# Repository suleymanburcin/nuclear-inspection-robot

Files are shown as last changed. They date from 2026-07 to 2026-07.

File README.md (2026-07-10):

# Nükleer Denetim Robotu

**TEKNOFEST 2026 · Nükleer Enerji Teknolojileri Tasarım Yarışması**
Uygulama Kategorisi — Robotik Sistem Tasarımı

Küçük ve mikro modüler reaktörlerde (SMR/MMR) insan girişi olmadan denetim yapmak üzere
geliştirilmiş, **keseli (marsupial)** mimariye sahip iki platformlu robotik sistem.

---

## Fikir

Kaza sonrası bir nükleer tesiste iki farklı problem vardır ve bunların çözümleri
birbiriyle çelişir:

- **Dış sahada** menzil ve yük taşıma kapasitesi gerekir → yüksek özgül enerjili yakıt
- **Reaktör binası içinde** kıvılcım ve egzoz üretilmemelidir → hidrojen birikimi riski

Literatürdeki robotlar tek platformlu ve tamamen elektriklidir; ikinci kısıtı sağlarlar
ama birincisinden ödün verirler.

Bu çalışma görevi **iki uzmanlaşmış platforma** ayırır:

| Platform | Tahrik | Görev |
|---|---|---|
| **Benzinli taşıyıcı** | 7 BG içten yanmalı, Ackermann direksiyon | Dış saha, menzil, yük |
| **Elektrikli yavru robot** | Deneyap Kart 1A, kayma-yönlendirmeli | Kapalı hacim, emisyonsuz |

Literatürdeki hibritler ağırlıklı olarak *hareket-modu* hibritleridir (tekerlek–palet,
tekerlek–bacak). Buradaki ise bir **enerji-modu hibrididir.**

Kapalı hacme yalnızca emisyonsuz robot girer. Kaza sonrası ortamda hidrojen birikimi
ihtimali göz önüne alındığında bu bir tercih değil, **güvenlik gereğidir.**

Taşıyıcı platform, atıl bir go-kart şasisinden yeniden kazanılmıştır.

---

## Sistem mimarisi

Dört katman, dört ayrı işlemci. Katmanlar fiziksel olarak ayrılmıştır; bu sayede hata
kaynağı ayrıştırılabilir ve alt sistemler paralel geliştirilebilir.

```
  ALGILAMA          KÖPRÜLEME          KARAR              EYLEYİCİ
  Arduino Leonardo  1. ESP32           Jetson Orin Nano   2. ESP32
  10 sensör         BNO055 yönelim     PyQt5 panel        6 eyleyici
       │                 │                  │                  ▲
       └──D0/D1─────────►└──GPIO2──────────►└──pin8────────────┘
          115.200            JSON              M,…*XOR
```

Buna ek olarak, karar katmanından **tamamen yalıtılmış** bir FPV hattı bulunur:
termal kamera ve radyasyon dedektörünün ekranları ortak bir kadrajda, analog video
üzerinden operatöre aktarılır. Jetson çökse dahi radyolojik ve termal durum
farkındalığı sürer.

---

## Doğrulanmış işlevler

- Manuel kontrollü sürüş: gaz, fren, direksiyon
- Çok modaliteli algılama: beş gaz kanalı (H₂, CO, LPG/duman, NH₃/CO₂, UOB),
  sıcaklık/nem/basınç, ultrasonik seviye, GNSS, dokuz eksen mutlak yönelim
- Her iki platformda üç eksenli manipülatör
- Elektrikli yavru robotun kablosuz denetimi ve emniyet zaman aşımı
- Çift kameralı görüş, RealSense derinlik akışı
- Karar katmanından bağımsız FPV hattı (termal + radyasyon)
- Yalıtılmış ağda salt-okunur panel yayını (MJPEG, çoklu istemci)
- Uzaktan kontrol: fiziksel joystick her zaman öncelikli

## Doğrulanmamış / kapsam dışı

Bunlar raporda da açıkça belirtilmiştir; hiçbiri görev senaryolarının başarı
ölçütüne dâhil değildir.

- **Otonom seyrüsefer** — planlama katmanı yazıldı, eyleyici katmanına bağlanmadı,
  saha denemesi yapılmadı. İç mekân modülünde **lokalizasyon yoktur**; robot kendi
  konumunu ölçmez, konum varsayılır.
- **Yüksek tork gerektiren manipülasyon** — mevcut aktüatör kapasitesi dışında.
- **Zırhlamanın fiziksel doğrulaması** — yalnızca Geant4 simülasyonu yapıldı,
  ışınlama testi yapılmadı.

---

## Radyasyon zırhlaması

COTS bileşenlerin literatürde bildirilen **~120 Gy** arıza eşiği veri olarak alınmış,
bu eşiğin altında kalınmasını sağlayacak zırhlama Geant4 ile boyutlandırılmıştır.
Böylece dayanım problemi, pahalı bileşen tedarikinden **ölçülebilir bir mühendislik
hesabına** dönüşmüştür.

| Malzeme | Gama 1,6 MeV | Nötron 2 MeV |
|---|---|---|
| WNiFe95 | %7,93 | %36,80 |
| **WNiFe97** | **%7,40** | **%36,22** |
| WNiCu97 | %7,53 | %36,37 |
| Cam (Pb + boro) | %57,18 | %70,88 |

Seçilen yapılandırma: **1 cm parafin + 4 cm WNiFe97**. Parafin hızlı nötronları elastik
saçılmayla yavaşlatır; tungsten alaşımı gama fotonlarını soğurur ve parafindeki nötron
yakalanmasından doğan ikincil gamaları da zayıflatır.

---

## Depo yapısı

```
geant4/           Zırhlama analizi: girdi makrosu, koşu çıktıları, kaynak
firmware/         Gömülü yazılım — dört Arduino eskizi
  leonardo_gas_sender/    Algılama katmanı
  esp32_1_bridge/         Köprüleme katmanı
  esp32_2_actuator/       Eyleyici katmanı
  deneyap_baby/           Elektrikli yavru robot
jetson/           Karar katmanı ve seyrüsefer modülleri
  remote_control/         Uzak istasyon istemcisi
cad/              Üç boyutlu baskı parçalarının teknik çizimleri
```

---

## Kurulum

### Gömülü kartlar (Arduino IDE)

> **ÖNEMLİ.** ESP32 kart tanımı yanlış seçilirse `Serial2` sessizce ölür.

```
Board            : ESP32 Dev Module      ← "Wrover Kit" DEĞİL
PSRAM            : Disabled
Flash Mode       : DIO
Flash Frequency  : 40MHz
Upload Speed     : 115200
Core Debug Level : None
```

PSRAM açıkken çekirdek **GPIO16 ve GPIO17'yi PSRAM için ayırır.** `Serial2` bu iki
pinde olduğundan komutlar hiç ulaşmaz. Firmware bunu derleme zamanında engeller:

```c
#ifdef BOARD_HAS_PSRAM
#error "PSRAM ACIK! GPIO16/17 PSRAM'e ayrilir, Serial2 calismaz."
#endif
```

Gerekli kütüphaneler: `ESP32Servo` · `Adafruit BNO055` · `Adafruit BME280` · `TinyGPS++`

### Wi-Fi kimlik bilgileri

`firmware/deneyap_baby/secrets_ornek.h` dosyasını `secrets.h` olarak kopyalayıp doldurun.
`secrets.h` `.gitignore` içindedir; **depoya yüklenmez.**

### Karar katmanı (Jetson Orin Nano)

```bash
pip3 install -r jetson/requirements.txt
python3 jetson/jetson_gas_dock.py
```

---

## Haberleşme protokolleri

| Hat | Biçim | Hız |
|---|---|---|
| Leonardo → 1. ESP32 | 17 alanlı çerçeve + XOR sağlama | 115.200 |
| 1. ESP32 → Jetson | JSON | 115.200 |
| Jetson → 2. ESP32 | `M,gaz,fren,dir,kolBaz,dirsek,parmak*XOR` | 115.200 |
| Jetson → Deneyap | `F,s1,s2,s3` (UDP yayını) | :4210 |
| Uzak istasyon → Jetson | `joyX,joyY` (UDP) | :9000 |

Komut hatlarında **XOR sağlama toplamı** kullanılır. Gürültülü bir hatta bozulan çerçeve,
eyleyiciye ulaşmadan elenir. Bu, gaz kelebeğinin yanlış bir baytla açılmasını engeller.

---

## Güvenlik

- Panel yayını (`:8080`) ve uzaktan kontrol (`:9000`) **yalıtılmış yerel ağda** kalmalıdır.
  Kimlik doğrulama ve TLS **yoktur**; internete açılmamalıdır. Yalıtım ağ düzeyinde
  sağlanır, uygulama düzeyinde değil.
- Yayın arayüzü **salt-okunurdur.** Yalnızca `GET` yöntemini ve üç tanımlı yolu işler;
  hiçbir eyleyici uç noktası yayımlamaz. Arayüz ele geçirilse dahi robota komut verilemez.
- Uzaktan kontrolde **fiziksel joystick her zaman önceliklidir.** Araç üzerindeki kol
  merkezden ayrıldığı anda uzak komut yok sayılır.
- Üç bağımsız emniyet katmanı: fiziksel öncelik → 800 ms uzak zaman aşımı →
  1500 ms eyleyici zaman aşımı (gaz kapanır).

---

## Geliştirme sırasında belgelenen hata sınıfları

Literatürde nadiren paylaşılan, gerçek bir gömülü sistemde karşılaşılan altı hata sınıfı
raporun 4.1.2.8 bölümünde kök nedenleriyle birlikte açıklanmıştır. Aralarında:

- **Kart tanımının PSRAM'li seçilmesi** → UART2 pinlerinin işgali → sessiz haberleşme kaybı
- **Kanal kapasitesi** — 9600 baud, 25 Hz'te üretilen çerçeveyi taşıyamaz (212 ms > 40 ms)
- **Sürücü asgari darbe genişliği** — adım motoru sürücüsünün gereksinimi
- **Sensör önyükleme penceresi** — BNO055'in I²C'ye hazır olma süresi

Bu bulguların paylaşılması, benzer sistemleri geliştirecek ekiplerin aynı hatalara
harcayacağı süreyi kısaltır.

---

## Maliyet

Toplam donanım maliyeti yaklaşık **129.045 ₺**. Ticari nükleer denetim robotlarının
maliyetinin çok altındadır; sistem tamamen ticari raf ürünü bileşenler ve açık kaynaklı
bir araç zinciri üzerine kuruludur. **Tescilli yazılım bağımlılığı yoktur.**

---

## Lisans ve atıf

TEKNOFEST 2026 Nükleer Enerji Teknolojileri Tasarım Yarışması kapsamında geliştirilmiştir.

Bu depoyu kullanır veya alıntılarsanız, projeye atıf yapmanız beklenir.

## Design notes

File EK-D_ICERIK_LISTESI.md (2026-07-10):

# Ek-D · Dijital Eklerin İçerik Listesi

Bu arşiv, Final Değerlendirme Raporu'nun **Ek-D** bölümünde tanımlanan yapıya birebir
uygundur.

| Klasör / dosya | İçerik | Durum |
|---|---|---|
| `geant4/utku.mac` | Zırhlama analizi girdi makrosu (Ek-A ile aynı) | ✅ |
| `geant4/output/*.txt` | Beş zırh yapılandırmasının tam koşu çıktıları | ✅ |
| `geant4/src/DetectorConstruction.cc` | Zırh malzemeleri ve geometri tanımı | ✅ |
| `firmware/leonardo_gas_sender/` | Algılama katmanı gömülü yazılımı | ✅ |
| `firmware/esp32_1_bridge/` | Köprüleme katmanı gömülü yazılımı | ✅ |
| `firmware/esp32_2_actuator/` | Eyleyici katmanı gömülü yazılımı | ✅ |
| `firmware/deneyap_baby/` | Elektrikli yavru robot gömülü yazılımı | ✅ |
| `jetson/requirements.txt` | Python paketlerinin sürüm listesi | ✅ Tablo 8.4’ten üretildi |
| `jetson/jetson_gas_dock.py` | Gösterge paneli ve MJPEG yayın sunucusu | ✅ |
| `jetson/remote_control/` | Uzak istasyon istemcisi | ✅ |
| `jetson/indoor_nav.py` | İç mekân yol planlama modülü | ✅ |
| `jetson/outdoor_nav.py` | Dış mekân rota takibi modülü | ✅ |
| `cad/` | Üç boyutlu baskı parçalarının teknik çizimleri | ✅ 12 STL |

## Ek-D'de listelenmeyen, arşive dâhil edilen dosyalar

| Dosya | Neden |
|---|---|
| `firmware/deneyap_baby/secrets_ornek.h` | Wi-Fi kimlik bilgisi şablonu; gerçek değerler depoda tutulmaz |
| `jetson/outdoor_nav_gui.py` | Dış mekân seyrüsefer izleme arayüzü |
| `jetson/rover_gcs.py` | Uydu haritalı yer kontrol istasyonu |

Bu üç dosya raporun Ek-C bölümünde kaynak kod olarak yer almaktadır.

---

## Geant4 koşu ayarları (çıktı dosyalarından doğrulandı)

| | |
|---|---|
| Sürüm | `geant4-11-03-patch-02 [MT]` |
| Fizik listesi | `QGSP_BERT_HP` |
| Birincil parçacık | 10⁶ / parçacık türü |

---

## Yüklemeden önce yapılacaklar

1. `geant4/output/CAM.txt` (cam yapılandırması koşu çıktısı) dosyasını ekleyin.
2. `cad/fpv_tutucu.stl` ve `cad/kol_taban_braketi.stl` adlandırmalarını doğrulayın.
3. `secrets.h` dosyasının arşivde **bulunmadığını** doğrulayın.

---

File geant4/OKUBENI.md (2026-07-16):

# geant4/ — Radyasyon Zırhlama Analizi

## Koşu ayarları (çıktı dosyalarından doğrulanmıştır)

| | |
|---|---|
| Geant4 sürümü | `geant4-11-03-patch-02 [MT]` (çok iş parçacıklı) |
| Fizik listesi | `QGSP_BERT_HP` |
| Birincil parçacık | 10⁶ / parçacık türü |
| Panel kesiti | 10 cm × 10 cm |

Dört çıktı dosyasının tamamı **aynı sürüm ve aynı fizik listesiyle** koşulmuştur;
karşılaştırma bu nedenle geçerlidir.

`QGSP_BERT_HP` seçimi, `_HP` uzantısı sayesinde 20 MeV altındaki nötronlar için
yüksek hassasiyetli veri kütüphanelerini kullanır. Nötron zırhlaması için gereklidir.

## Mevcut dosyalar

| Dosya | İçerik |
|---|---|
| `src/DetectorConstruction.cc` | Zırh malzemeleri ve geometri tanımı (8 malzeme) |
| `output/WNIFE97.txt` | Tungsten–nikel–demir %97 |
| `output/WNIFE95.txt` | Tungsten–nikel–demir %95 |
| `output/WNICU97.txt` | Tungsten–nikel–bakır %97 |
| `output/WNICU95.txt` | Tungsten–nikel–bakır %95 |

## `utku.mac` hakkında

Makro; 1 cm parafin + 4 cm zırh geometrisini kurar, panel kesitini 10 cm × 10 cm yapar
ve on beş koşu yürütür (her biri 10⁶ birincil parçacık):

| Parçacık | Enerji |
|---|---|
| Gama × 6 | 59,5 keV · 364 keV · 605 keV · 662 keV · 796 keV · 1596 keV |
| Beta (e⁻) × 4 | 606 · 512 · 546 keV · 2,28 MeV |
| Alfa × 2 | 5,16 · 5,49 MeV |
| Nötron × 3 | 0,025 eV (termal) · 100 keV (epitermal) · 2 MeV (hızlı) |

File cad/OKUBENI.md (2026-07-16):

# cad/ — Üç Boyutlu Baskı Parçaları

Tüm dosyalar ikili (binary) STL biçimindedir ve bütünlük denetiminden geçmiştir.

## Mevcut parçalar

| Dosya | Üçgen | Parça |
|---|---|---|
| `gaz1.STL` – `gaz4.STL` | 716 / 770 / 1376 / 656 | Gaz kelebeği servosu braketi |
| `fren1.STL`, `fren2.STL` | 766 / 720 | Fren servosu braketi |
| `direksiyon1.STL`, `direksiyon2.STL` | 2112 / 826 | Direksiyon adım motoru braketi |
| `ustkapak.STL` | 1316 | Algılama muhafazası — üst kapak (230 × 200 × 52 mm) |
| `altkapak.STL` | 628 | Algılama muhafazası — alt kapak (230 × 200 × 10 mm) |
| `fpv_tutucu.stl` | 1718 | FPV kamera ve ölçüm cihazı tutucusu (122 × 100 × 190 mm) |
| `kol_taban_braketi.stl` | 26864 | Kol taban adım motoru braketi (75 × 65 × 94 mm) |

.

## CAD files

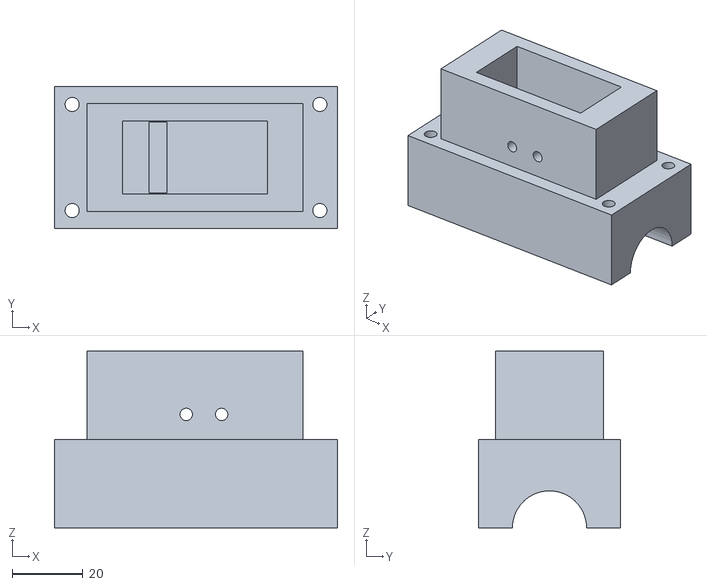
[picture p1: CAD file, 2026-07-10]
cad/gaz3.STL
80.0 x 40.0 x 50.0

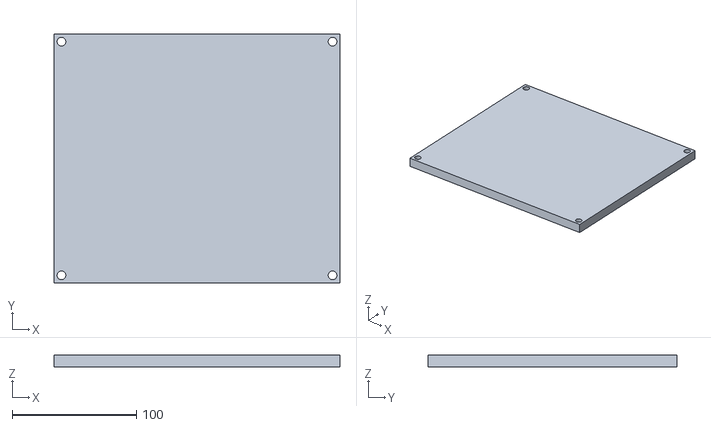
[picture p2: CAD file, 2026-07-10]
cad/altkapak.STL
230.0 x 200.0 x 10.0

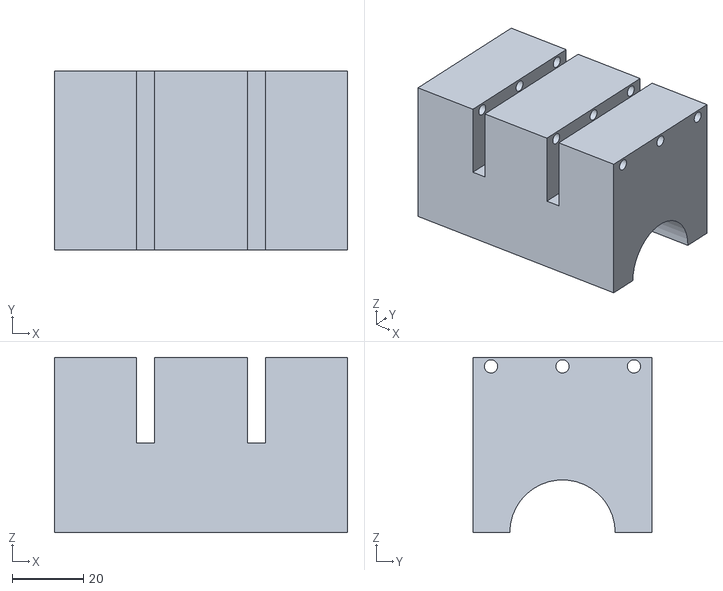
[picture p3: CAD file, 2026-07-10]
cad/direksiyon1.STL
82.0 x 50.0 x 49.0

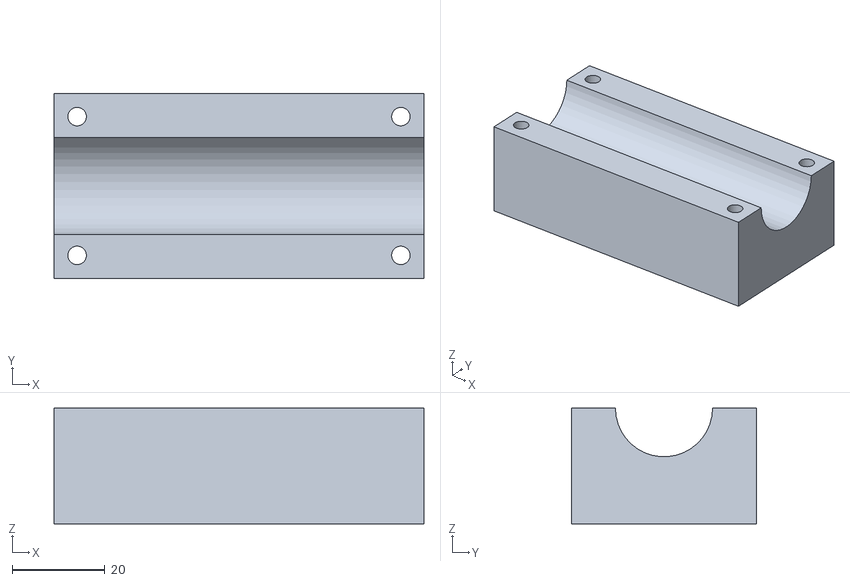
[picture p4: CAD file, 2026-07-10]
cad/gaz1.STL
80.0 x 40.0 x 25.0

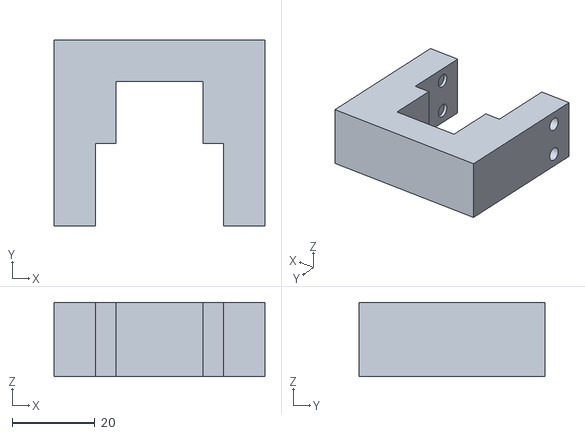
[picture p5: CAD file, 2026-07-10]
cad/gaz4.STL
51.0 x 45.0 x 18.0

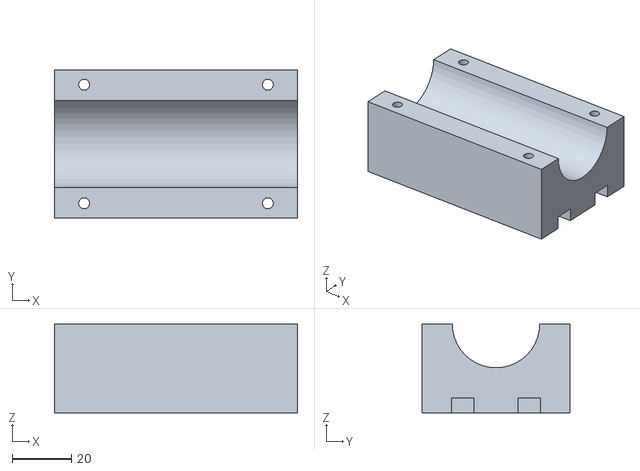
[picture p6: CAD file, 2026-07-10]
cad/direksiyon2.STL
82.0 x 50.0 x 30.0

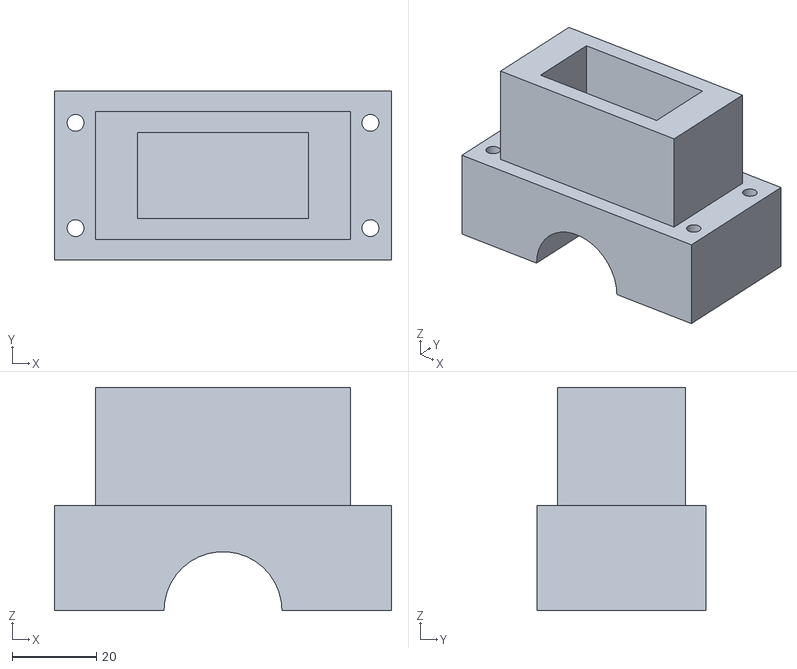
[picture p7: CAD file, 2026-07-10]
cad/fren1.STL
80.0 x 40.0 x 53.0

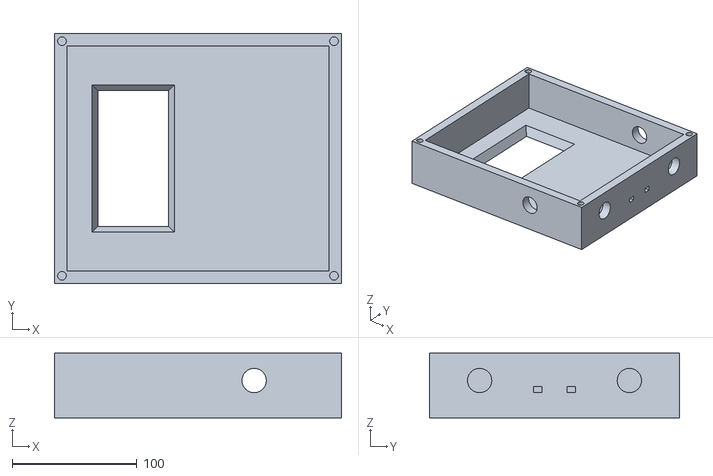
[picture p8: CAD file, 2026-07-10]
cad/ustkapak.STL
230.0 x 200.0 x 52.0

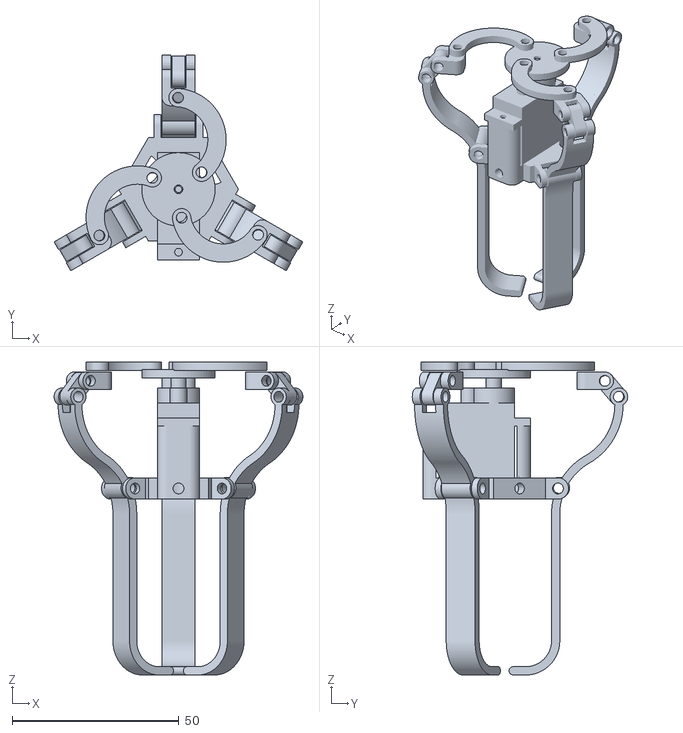
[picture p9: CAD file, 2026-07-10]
cad/kol_taban_braketi.stl
74.7 x 64.7 x 94.0

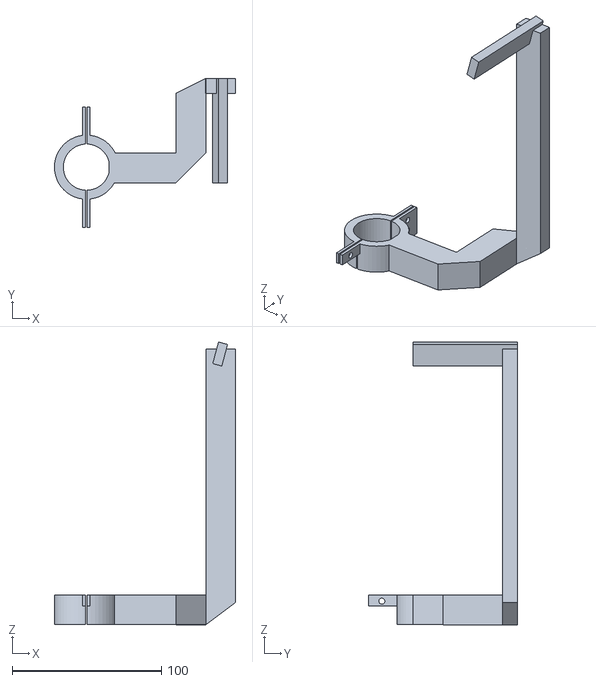
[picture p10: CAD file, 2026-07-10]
cad/fpv_tutucu.stl
121.5 x 100.0 x 189.8

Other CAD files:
cad/gaz2.STL
cad/fren2.STL

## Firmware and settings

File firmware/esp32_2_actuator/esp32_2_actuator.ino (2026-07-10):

/*
 * ============ 2. ESP32 - MOTOR + ROBOT KOL KONTROL ============
 * Jetson'dan komut alir, motorlari + robot kolu surer. SENSOR YOK.
 *
 * BAGLANTI:
 *   Jetson ttyTHS1 TX (pin 8, 3.3V) --> 2. ESP32 GPIO16 (RX2)
 *   Jetson GND (pin 6)              --> 2. ESP32 GND      [ORTAK GND SART]
 *
 * SURUS MOTORLARI:
 *   Servo GAZ    -> GPIO18   (6V ayri guc)
 *   Servo FREN   -> GPIO19
 *   Step DIREKS. -> PUL GPIO26, DIR GPIO27   (MD5042 + 57HB84)
 *
 * ROBOT KOL:
 *   Step TABAN   -> PUL GPIO25, DIR GPIO33   (MD5042 + 57HB84, aynisi)
 *   Servo DIRSEK -> GPIO23    (0-180)
 *   Servo PARMAK -> GPIO22     (0-180, kiskac ac/kapa)
 *   TUM STEP PUL+/DIR+ -> 5V | TUM GUC ORTAK GND
 *
 * KOMUT PROTOKOLU (Jetson -> ESP32, \n sonlu):
 *   M,<gaz>,<fren>,<dir>,<kolBaz>,<dirsek>,<parmak>\n
 *     gaz    : 0..90    (gaz servosu)
 *     fren   : 0..90    (fren servosu)
 *     dir    : -STEER_MAX_LEFT..+STEER_MAX_RIGHT (asimetrik; 0=duz)
 *     kolBaz : -600..600 (kol taban step hedef; 0=merkez)
 *     dirsek : 0..180   (dirsek servosu)
 *     parmak : 0..180   (parmak/kiskac servosu)
 *   Ornek: M,40,0,20,100,90,180  -> yarim gaz, saga, kol saga, dirsek orta, parmak acik
 *   Komut gelmezse (CMD_TIMEOUT = 1500ms): GUVENLIK -> gaz kapa, fren serbest.
 *
 * ACILISTA: direksiyon VE kol tabani ELLE ORTA/DUZ yap (merkez=0).
 * Kutuphane: ESP32Servo
 */

#include <ESP32Servo.h>

// ============================================================================
//  DERLEME KORUMASI — PSRAM
//  PSRAM acikken ESP32 cekirdegi GPIO16 ve GPIO17'yi PSRAM icin ayirir.
//  Serial2 bu iki pinde oldugundan Jetson komutlari HIC ULASMAZ.
//  Belirti: "E (91) psram: PSRAM ID read error" + surekli [GUVENLIK] mesaji.
//  Cozum:   Tools > Board: "ESP32 Dev Module"   ve   Tools > PSRAM: Disabled
// ============================================================================
#ifdef BOARD_HAS_PSRAM
#error "PSRAM ACIK! GPIO16/17 PSRAM'e ayrilir, Serial2 calismaz. Tools > PSRAM: Disabled yap."
#endif


// ---- Jetson komut hatti ----
#define JETSON_RX 16
#define JETSON_TX 17
#define CMD_BAUD  115200

// ---- Surus motor pinleri ----
#define SERVO_GAS_PIN   18   // (yer degistirildi: eskiden 19, ters calisiyordu)
#define SERVO_BRAKE_PIN 19   // (yer degistirildi: eskiden 18)
#define STEER_PUL_PIN   26
#define STEER_DIR_PIN   27

// ---- Robot kol pinleri ----
#define ARM_PUL_PIN     25   // kol taban step
#define ARM_DIR_PIN     33
#define SERVO_ELBOW_PIN 23   // dirsek
#define SERVO_GRIP_PIN  22   // parmak/kiskac (5ten 22ye tasindi)

Servo servoGas, servoBrake, servoElbow, servoGrip;

// ---- Aci limitleri ----
const int GAS_MIN = 0, GAS_MAX = 90;
const int BRK_MIN = 0, BRK_MAX = 90;
const int ELB_MIN = 0, ELB_MAX = 180;
const int GRP_MIN = 0, GRP_MAX = 180;

// ---- Direksiyon step ----
// ---- DIREKSIYON ACI SINIRLARI (asimetrik) ----
// Aci -> adim donusumu: adim = derece * STEPS_PER_REV * GEAR / 360
//   STEPS_PER_REV : surucunun mikroadim ayari (tam tur basina adim)
//   STEER_GEAR    : motor mili -> direksiyon mili orani (dogrudan tahrik = 1.0)
// Degistirmek icin SADECE asagidaki dort satiri duzenle.
// !!! STEER_STEPS_PER_REV, MD5042'nin DIP anahtarindaki mikroadim ayariyla
//     BIREBIR AYNI OLMALI. Uyusmazsa direksiyon eksik/fazla doner.
//     (Onceki deger 400 idi; olculen donusun 1/3 kalmasi uzerine 1200 yapildi.)
const float STEER_STEPS_PER_REV = 1200.0;  // MD5042 mikroadim ayari (DIP'ten oku!)
const float STEER_GEAR          = 1.0;     // dogrudan tahrik (disli/kayis varsa oran gir)
const float STEER_DEG_RIGHT     = 15.0;    // saga azami aci
const float STEER_DEG_LEFT      = 30.0;    // sola azami aci

const long STEER_MAX_RIGHT = (long)(STEER_DEG_RIGHT * STEER_STEPS_PER_REV * STEER_GEAR / 360.0 + 0.5);  // 50 adim
const long STEER_MAX_LEFT  = (long)(STEER_DEG_LEFT  * STEER_STEPS_PER_REV * STEER_GEAR / 360.0 + 0.5);  // 100 adim
const int  STEER_MIN_US = 600;   // darbe 200us + bekleme (adim hizi)
long steerCurrent = 0, steerTarget = 0;
uint32_t lastSteerUs = 0;

// ---- Kol taban step ----
const long ARM_MAX    = 600;   // kol taban +-600 adim (~270 derece, 6 kat)
const int  ARM_MIN_US = 1500;  // kol yavas donsun (adimlar arasi daha genis)
long armCurrent = 0, armTarget = 0;
uint32_t lastArmUs = 0;

// ---- Komut alimi ----
char cmdBuf[80];
uint8_t cmdLen = 0;
uint32_t lastCmdMs = 0;
const uint32_t CMD_TIMEOUT = 1500;  // joystick ~1Hz geldigi icin genis tut (gaz kesilmesin)
bool timeoutWarned = false;   // guvenlik uyarisi bir kez bassin

// ---- Hat kalitesi sayaclari (gurultu teshisi) ----
uint32_t okCount = 0;        // gecerli komut
uint32_t badCount = 0;       // bozuk / sagalama tutmayan satir
uint32_t lastErrMs = 0;      // hata mesajini saniyede 1 kez bas
uint32_t lastStatMs = 0;     // 5 saniyede bir ozet
const bool VERBOSE_HAM = false;  // true yaparsan her satiri ham basar

// Genel bloklamayan step surucu (hangi motor olursa)
void stepTickGeneric(long &cur, long tgt, uint32_t &lastUs, int minUs,
                     int pulPin, int dirPin) {
  if (cur == tgt) return;
  uint32_t now = micros();
  if (now - lastUs < (uint32_t)minUs) return;
  lastUs = now;
  bool dir = (tgt > cur);
  digitalWrite(dirPin, dir ? HIGH : LOW);
  delayMicroseconds(10);          // yon oturması icin
  digitalWrite(pulPin, HIGH);
  delayMicroseconds(100);         // HIGH darbe genisligi (MD5042 icin yeterli)
  digitalWrite(pulPin, LOW);
  delayMicroseconds(100);         // LOW arasi (darbe net ayrilsin)
  cur += dir ? 1 : -1;
}

// Guvenli mod: gaz kapa, fren serbest. Kol/direksiyon oldugu yerde kalir.
void safeStop() {
  servoGas.write(GAS_MIN);
  servoBrake.write(BRK_MIN);
  // step hedefleri degismez -> son konumda kalir (kol dusmez)
}

// Sagalama: "M,...*7F" -> '*' oncesi tum karakterlerin XOR'u, hex olarak.
// '*' yoksa (eski panel) sagalama atlanir, komut kabul edilir.
// -1 = sagalama yok | 0 = TUTMADI | 1 = TUTTU
int checksumOk(const char *line) {
  const char *star = strchr(line, '*');
  if (star == NULL) return -1;
  uint8_t x = 0;
  for (const char *q = line; q < star; q++) x ^= (uint8_t)(*q);
  uint8_t got = (uint8_t)strtol(star + 1, NULL, 16);
  return (x == got) ? 1 : 0;
}

// Komut isle: M,gaz,fren,dir,kolBaz,dirsek,parmak[*XOR] (6 sayi)
bool parseCmd(char *line) {
  // Bastaki cop/gurultu byte'larini atla, "M," ile baslayan yeri bul
  char *m = strstr(line, "M,");
  if (m == NULL) return false;
  line = m;   // M,'den itibaren isle (bastaki cop atlanir)
  if (line[0] != 'M' || line[1] != ',') return false;

  // Sagalama varsa DOGRULA. Tutmuyorsa satiri sessizce at (gurultu).
  int cs = checksumOk(line);
  if (cs == 0) { badCount++; return false; }

  // '*' varsa oradan kes -> strtok sayilari temiz alsin
  char *star = strchr(line, '*');
  if (star) *star = '\0';

  char *p = line + 2;
  char *tok = strtok(p, ",");
  int n = 0;
  int gaz=0, fren=0, dirsek=0, parmak=0;
  long dir=0, kolBaz=0;
  while (tok) {
    long v = atol(tok);
    switch (n) {
      case 0: gaz    = (int)v; break;
      case 1: fren   = (int)v; break;
      case 2: dir    = v;      break;
      case 3: kolBaz = v;      break;
      case 4: dirsek = (int)v; break;
      case 5: parmak = (int)v; break;
    }
    n++;
    tok = strtok(NULL, ",");
  }
  if (n != 6) return false;

  // limitlere kis (guvenlik)
  gaz    = constrain(gaz,    GAS_MIN, GAS_MAX);
  fren   = constrain(fren,   BRK_MIN, BRK_MAX);
  dir    = constrain(dir,   -STEER_MAX_LEFT, STEER_MAX_RIGHT);   // asimetrik: sol 30 derece, sag 15 derece
  kolBaz = constrain(kolBaz, -ARM_MAX,  ARM_MAX);
  dirsek = constrain(dirsek, ELB_MIN, ELB_MAX);
  parmak = constrain(parmak, GRP_MIN, GRP_MAX);

  // uygula
  servoGas.write(gaz);
  servoBrake.write(fren);
  steerTarget = dir;
  armTarget   = kolBaz;
  servoElbow.write(dirsek);
  servoGrip.write(parmak);

  lastCmdMs = millis();
  timeoutWarned = false;   // komut geldi -> guvenlik uyarisini sifirla
  okCount++;

  // --- DEBUG: gelen komutu ve uygulanan degerleri Serial'e (USB) bas ---
  Serial.print("[KOMUT] gaz="); Serial.print(gaz);
  Serial.print(" fren="); Serial.print(fren);
  Serial.print(" dir="); Serial.print(dir);
  Serial.print(" kolBaz="); Serial.print(kolBaz);
  Serial.print(" dirsek="); Serial.print(dirsek);
  Serial.print(" parmak="); Serial.println(parmak);

  return true;
}

void setup() {
  Serial.begin(115200);
  Serial2.begin(CMD_BAUD, SERIAL_8N1, JETSON_RX, JETSON_TX);

  // Step motorlar (direksiyon + kol taban)
  pinMode(STEER_PUL_PIN, OUTPUT); pinMode(STEER_DIR_PIN, OUTPUT);
  pinMode(ARM_PUL_PIN, OUTPUT);   pinMode(ARM_DIR_PIN, OUTPUT);
  digitalWrite(STEER_PUL_PIN, LOW); digitalWrite(STEER_DIR_PIN, LOW);
  digitalWrite(ARM_PUL_PIN, LOW);   digitalWrite(ARM_DIR_PIN, LOW);
  steerCurrent = 0; steerTarget = 0;    // ACILISTA DIREKSIYON ELLE DUZ
  armCurrent = 0;   armTarget = 0;      // ACILISTA KOL TABANI ELLE ORTA

  // Servolar (4 adet -> 4 timer)
  ESP32PWM::allocateTimer(0);
  ESP32PWM::allocateTimer(1);
  ESP32PWM::allocateTimer(2);
  ESP32PWM::allocateTimer(3);
  servoGas.setPeriodHertz(50);   servoBrake.setPeriodHertz(50);
  servoElbow.setPeriodHertz(50); servoGrip.setPeriodHertz(50);
  servoGas.attach(SERVO_GAS_PIN, 500, 2400);
  servoBrake.attach(SERVO_BRAKE_PIN, 500, 2400);
  servoElbow.attach(SERVO_ELBOW_PIN, 500, 2400);
  servoGrip.attach(SERVO_GRIP_PIN, 500, 2400);

  // baslangic: gaz kapali, fren serbest, dirsek orta, parmak kapali
  servoGas.write(GAS_MIN);
  servoBrake.write(BRK_MIN);
  servoElbow.write(90);
  servoGrip.write(GRP_MIN);

  // Baud ve pinleri bas -> uc cihazin ayarini karsilastirmak kolay olsun
  Serial.print("[UART] Serial2 RX=GPIO"); Serial.print(JETSON_RX);
  Serial.print("  baud="); Serial.println(CMD_BAUD);
  Serial.println("[UART] Panel (BAUD) ve 1.ESP32 (JETSON_BAUD) AYNI olmali!");

  // Hesaplanan limitleri bas (yanlis mikroadim/oran ayarini erken yakalamak icin)
  Serial.print("[LIMIT] direksiyon: sag +"); Serial.print(STEER_MAX_RIGHT);
  Serial.print(" adim ("); Serial.print(STEER_DEG_RIGHT, 1); Serial.print(" derece)  |  sol -");
  Serial.print(STEER_MAX_LEFT); Serial.print(" adim ("); Serial.print(STEER_DEG_LEFT, 1);
  Serial.println(" derece)");
  Serial.print("[LIMIT] kol taban: +-"); Serial.print(ARM_MAX); Serial.println(" adim");
  Serial.println("[UYARI] Jetson paneli dir icin +-300 gonderiyor; burada kisilir.");

  Serial.println("{\"motor\":\"2.ESP32 hazir. Direksiyon+kol ELLE ORTA yap. Jetson komutu bekleniyor.\"}");

  lastCmdMs = millis();
}

void loop() {

  // Jetson'dan komut topla
  while (Serial2.available()) {
    char c = Serial2.read();
    if (c == '\n') {
      cmdBuf[cmdLen] = '\0';
      if (cmdLen > 0) {
        if (VERBOSE_HAM) { Serial.print("[HAM] "); Serial.println(cmdBuf); }
        if (!parseCmd(cmdBuf)) {
          badCount++;
          // Gurultulu hatta ekrani bogmamak icin saniyede en fazla 1 uyari
          if (millis() - lastErrMs > 1000) {
            lastErrMs = millis();
            Serial.println("[BOZUK] satir elendi (gurultu). Ozet icin 5 sn bekle.");
          }
        }
      }
      cmdLen = 0;
    } else if (c != '\r') {
      if (cmdLen < sizeof(cmdBuf) - 1) cmdBuf[cmdLen++] = c;
      else cmdLen = 0;
    }
  }

  // Guvenlik: komut kesilirse dur
  if (millis() - lastCmdMs > CMD_TIMEOUT) {
    if (!timeoutWarned) {
      Serial.print("[GUVENLIK] "); Serial.print(CMD_TIMEOUT);
      Serial.println(" ms komut yok -> gaz kapandi, kol/direksiyon sabit.");
      timeoutWarned = true;
    }
    safeStop();
  }

  // ---- 5 saniyede bir HAT KALITESI ozeti ----
  if (millis() - lastStatMs > 5000) {
    lastStatMs = millis();
    uint32_t toplam = okCount + badCount;
    if (toplam > 0) {
      float oran = 100.0 * okCount / toplam;
      Serial.print("[HAT] gecerli="); Serial.print(okCount);
      Serial.print("  bozuk=");       Serial.print(badCount);
      Serial.print("  basari=%");     Serial.print(oran, 1);
      if (oran > 98)      Serial.println("  -> hat TEMIZ");
      else if (oran > 80) Serial.println("  -> hat gurultulu (kablo/GND kontrol)");
      else                Serial.println("  -> hat COK KOTU: ortak GND yok veya baud yanlis");
    } else {
      Serial.println("[HAT] hic satir gelmedi.");
    }
    okCount = 0; badCount = 0;
  }

  // Iki step motoru da bloklamadan surekli adimla
  stepTickGeneric(steerCurrent, steerTarget, lastSteerUs, STEER_MIN_US,
                  STEER_PUL_PIN, STEER_DIR_PIN);   // direksiyon
  stepTickGeneric(armCurrent, armTarget, lastArmUs, ARM_MIN_US,
                  ARM_PUL_PIN, ARM_DIR_PIN);       // kol taban
}

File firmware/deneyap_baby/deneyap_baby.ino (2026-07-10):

/*
 * ====== DENEYAP KART - ELEKTRIKLI ROBOT (WiFi + UDP) ======
 * Skid-steer, CALISAN Bluetooth kodunun pin duzenine gore (kablolar ayni).
 *   Sag motor: D0/D1 (yon) | Sol motor: D8/D7 (yon) | PWM: D9 (hiz, her iki taraf)
 * Jetson/PC hotspot'una baglanir, UDP broadcast komut dinler.
 *
 * WiFi: PC/Jetson mobil hotspot (2.4 GHz)
 *   Ag: "<AGINIZIN_ADI>"  Sifre: "<PAROLA>"  UDP port: 4210
 *
 * KOMUTLAR (UDP paket): "F,s1,s2,s3,s4"
 *   F ileri | B geri | L sola | R saga | S dur
 *   s1..s4 servo acilari (0-180)
 *
 * Arduino IDE: Board = "Deneyap Kart 1A" (Dydk1a) SECILI OLMALI!
 */

#include <WiFi.h>
#include <WiFiUdp.h>
#include <ESP32Servo.h>

// ---- WiFi ----
// WiFi kimlik bilgileri ayri dosyada tutulur (GitHub'a yuklenmez).
// "secrets_ornek.h" dosyasini "secrets.h" olarak kopyalayip doldurun.
#include "secrets.h"   // WIFI_SSID, WIFI_PASS
const uint16_t UDP_PORT = 4210;
WiFiUDP udp;
char pkt[32];

// ---- Motor pinleri (CALISAN kod ile ayni) ----
int motor1_IN1 = D0;   // sag
int motor1_IN2 = D1;
int motor2_IN1 = D8;   // sol
int motor2_IN2 = D7;
int motor3_IN1 = D0;   // sag (paralel)
int motor3_IN2 = D1;
int motor4_IN1 = D8;   // sol (paralel)
int motor4_IN2 = D7;
int pwmPin1 = D9;      // sag PWM
int pwmPin2 = D9;      // sol PWM (ayni pin)
const int pwmChannel1 = 0;
const int pwmChannel2 = 1;
const int pwmFreq = 5000;
const int pwmResolution = 8;

// ---- Servo pinleri (bos, PWM'li) ----
// NOT: D7 sol motorda, D9 PWM'de. Servolar icin D4,D5,D6 + D10 kullaniyoruz.
#define S1_PIN D4    // en alt servo (taban)
#define S2_PIN D5    // bir ust servo (orta eklem)
#define S3_PIN D6    // sondaki servo (kiskac AC/KAPA - butondan)
Servo s1, s2, s3;    // 3 servo

uint32_t lastCmdMs = 0;
bool timeoutWarned = false;
const uint32_t CMD_TIMEOUT = 1500;

void setPWM(int dutyCycle) {
  ledcWrite(pwmChannel1, dutyCycle);
  ledcWrite(pwmChannel2, dutyCycle);
}

// --- Hareket fonksiyonlari (CALISAN koddan birebir) ---
void forward() {
  digitalWrite(motor1_IN1, HIGH); digitalWrite(motor1_IN2, LOW);
  digitalWrite(motor3_IN1, HIGH); digitalWrite(motor3_IN2, LOW);
  digitalWrite(motor2_IN1, HIGH); digitalWrite(motor2_IN2, LOW);
  digitalWrite(motor4_IN1, HIGH); digitalWrite(motor4_IN2, LOW);
  setPWM(128);
}
void backward() {
  digitalWrite(motor1_IN1, LOW); digitalWrite(motor1_IN2, HIGH);
  digitalWrite(motor3_IN1, LOW); digitalWrite(motor3_IN2, HIGH);
  digitalWrite(motor2_IN1, LOW); digitalWrite(motor2_IN2, HIGH);
  digitalWrite(motor4_IN1, LOW); digitalWrite(motor4_IN2, HIGH);
  setPWM(128);
}
void turnRight() {
  digitalWrite(motor1_IN1, LOW); digitalWrite(motor1_IN2, HIGH);
  digitalWrite(motor3_IN1, LOW); digitalWrite(motor3_IN2, HIGH);
  digitalWrite(motor2_IN1, HIGH); digitalWrite(motor2_IN2, LOW);
  digitalWrite(motor4_IN1, HIGH); digitalWrite(motor4_IN2, LOW);
  setPWM(90);
}
void turnLeft() {
  digitalWrite(motor1_IN1, HIGH); digitalWrite(motor1_IN2, LOW);
  digitalWrite(motor3_IN1, HIGH); digitalWrite(motor3_IN2, LOW);
  digitalWrite(motor2_IN1, LOW); digitalWrite(motor2_IN2, HIGH);
  digitalWrite(motor4_IN1, LOW); digitalWrite(motor4_IN2, HIGH);
  setPWM(90);
}
void stopAll() {
  digitalWrite(motor1_IN1, LOW); digitalWrite(motor1_IN2, LOW);
  digitalWrite(motor2_IN1, LOW); digitalWrite(motor2_IN2, LOW);
  digitalWrite(motor3_IN1, LOW); digitalWrite(motor3_IN2, LOW);
  digitalWrite(motor4_IN1, LOW); digitalWrite(motor4_IN2, LOW);
  setPWM(0);
}

void setup() {
  Serial.begin(115200);
  pinMode(motor1_IN1, OUTPUT); pinMode(motor1_IN2, OUTPUT);
  pinMode(motor2_IN1, OUTPUT); pinMode(motor2_IN2, OUTPUT);
  pinMode(motor3_IN1, OUTPUT); pinMode(motor3_IN2, OUTPUT);
  pinMode(motor4_IN1, OUTPUT); pinMode(motor4_IN2, OUTPUT);
  // PWM (calisan koddaki gibi)
  ledcSetup(pwmChannel1, pwmFreq, pwmResolution);
  ledcAttachPin(pwmPin1, pwmChannel1);
  ledcSetup(pwmChannel2, pwmFreq, pwmResolution);
  ledcAttachPin(pwmPin2, pwmChannel2);
  stopAll();

  // Servolar (sirayla baslat - ani akim koruma)
  ESP32PWM::allocateTimer(2);
  ESP32PWM::allocateTimer(3);
  s1.setPeriodHertz(50); s2.setPeriodHertz(50);
  s3.setPeriodHertz(50);
  s1.attach(S1_PIN, 500, 2400); s1.write(90); delay(120);  // en alt orta
  s2.attach(S2_PIN, 500, 2400); s2.write(90); delay(120);  // bir ust orta
  s3.attach(S3_PIN, 500, 2400); s3.write(0);  delay(120);  // kiskac kapali basla

  delay(500);
  WiFi.mode(WIFI_STA);
  WiFi.begin(WIFI_SSID, WIFI_PASS);
  Serial.print("WiFi baglaniyor");
  uint32_t t0 = millis();
  while (WiFi.status() != WL_CONNECTED && millis() - t0 < 20000) {
    delay(400); Serial.print(".");
  }
  if (WiFi.status() == WL_CONNECTED) {
    Serial.println();
    Serial.print("BAGLANDI. IP: "); Serial.println(WiFi.localIP());
    udp.begin(UDP_PORT);
    Serial.printf("UDP dinleniyor port %d\n", UDP_PORT);
  } else {
    Serial.println("\nWiFi BAGLANAMADI - ag/sifre/hotspot kontrol");
  }
  lastCmdMs = millis();
}

void loop() {
  if (WiFi.status() != WL_CONNECTED) {
    stopAll();
    WiFi.begin(WIFI_SSID, WIFI_PASS);
    delay(500);
    return;
  }

  int n = udp.parsePacket();
  if (n > 0) {
    int len = udp.read(pkt, sizeof(pkt) - 1);
    if (len > 0) {
      pkt[len] = '\0';
      Serial.print("[HAM] "); Serial.println(pkt);
      char c = pkt[0];
      const char* hareket = "?";
      switch (c) {
        case 'F': backward();  hareket="ILERI"; break;   // F->geri fonk (ters duzeltme)
        case 'B': forward();   hareket="GERI";  break;   // B->ileri fonk
        case 'L': turnRight(); hareket="SOLA";  break;   // L->sag fonk (ters duzeltme)
        case 'R': turnLeft();  hareket="SAGA";  break;   // R->sol fonk
        case 'S': stopAll();   hareket="DUR";   break;
        default:  hareket="GECERSIZ"; break;
      }
      int sv[4] = {-1,-1,-1,-1};
      char *p = strchr(pkt, ',');
      if (p) {
        char *tok = strtok(p + 1, ",");
        int i = 0;
        while (tok && i < 4) { sv[i++] = atoi(tok); tok = strtok(NULL, ","); }
        if (sv[0] >= 0) s1.write(constrain(sv[0], 0, 180));  // en alt
        if (sv[1] >= 0) s2.write(constrain(sv[1], 0, 180));  // bir ust
        if (sv[2] >= 0) s3.write(constrain(sv[2], 0, 180));  // kiskac (ac/kapa)
      }
      lastCmdMs = millis();
      timeoutWarned = false;
      Serial.print("[KOMUT] hareket="); Serial.print(hareket);
      Serial.print(" servo="); Serial.print(sv[0]); Serial.print(",");
      Serial.print(sv[1]); Serial.print(","); Serial.print(sv[2]);
      Serial.print(","); Serial.println(sv[3]);
    }
  }

  if (millis() - lastCmdMs > CMD_TIMEOUT) {
    if (!timeoutWarned) {
      Serial.println("[GUVENLIK] Komut kesildi -> motorlar durduruldu.");
      timeoutWarned = true;
    }
    stopAll();
  }
}
